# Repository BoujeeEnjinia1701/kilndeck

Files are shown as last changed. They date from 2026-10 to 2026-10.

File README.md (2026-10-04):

# KilnDeck

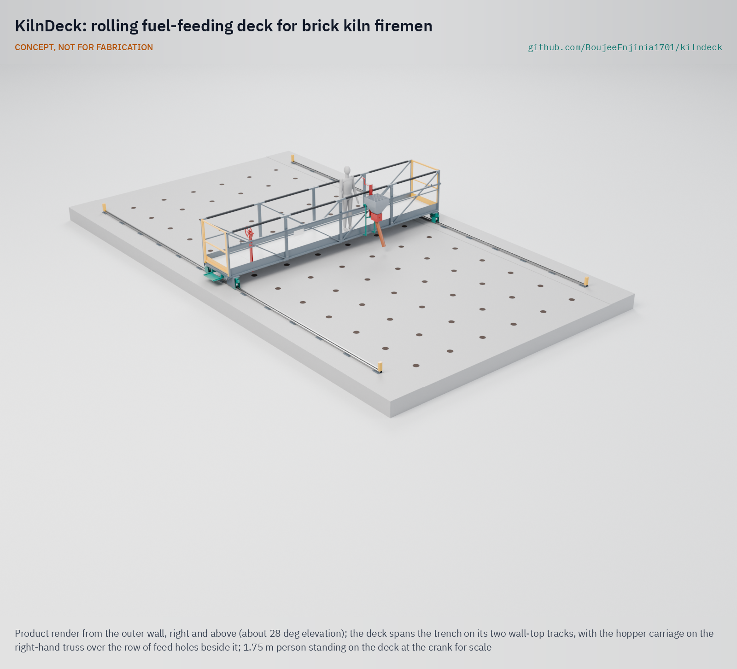
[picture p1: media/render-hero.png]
KilnDeck: rolling fuel-feeding deck for brick kiln firemen


     

**Area:** Sustainable housing · **TRL:** 3 of 9 (proof of concept on paper) · **Value-engineering target:** USD 3,500 (estimated cost of the constructable design USD 2,627) · **Difficulty:** 4 of 5

Carries kiln firemen on a railed rolling deck so they feed fuel without standing on the ash crust over the fire.

> CONCEPT, NOT FOR FABRICATION. KilnDeck is a TRL 3 design on paper: it has not been built or tested.

## Concept rationale

The fireman's job is to feed small amounts of fuel into many holes, over and over. The hazard is where he stands to do it: on the crust above the fire. KilnDeck moves him off the crust. A deck with a guardrail spans the trench from wall to wall and rolls along the kiln on two tracks laid on the wall tops, so nothing rests on the crust. The fireman moves the deck from row to row with a hand wheel, pushes a hopper carriage along the side of the deck to each feed hole, and turns a crank to drop a measured dose through a swing spout. His feet stay on an insulated floor, behind a 1.1 m guardrail.

The metering rotor also serves the kiln. Research in Bangladesh found that training firemen in continuous fuel feeding was part of an intervention that cut fuel use and emissions ([Luby Lab, Stanford](https://lubylab.stanford.edu/brick-kiln-intervention-trial); [Stanford Impact Labs](https://impact.stanford.edu/news/cleaner-brick-manufacturing-bangladesh)). A rotor that gives the same small dose each pocket makes steady feeding easier. Keeping the deck manual and open means kiln owners can have it built by local fabricators without power at the kiln top.

## Burning platform

South Asia has about 51,450 fixed-chimney bull's trench kilns: about 35,000 in India, 11,500 in Pakistan, 4,500 in Bangladesh and 450 in Nepal. In each, two firemen standing on top of the kiln feed fuel through feed holes every 15 to 20 minutes, each round lasting 5 to 10 minutes ([Greentech Knowledge Solutions, 2014](https://www.shareweb.ch/site/Climate-Change-and-Environment/about%20us/about%20gpcc/Documents/01%20Fixed%20Chimney%20Bulls%20Trench%20Kiln%20(FCBTK).pdf)). Firemen interviewed in India described flames burning their trousers and their feet burning in the heat, with wooden slippers as their only protection ([The Migration Story](https://themigrationstory.com/post/braving-the-heat-to-bake-bricks/)).

The worst outcome is a fall into the fire. On 18 June 2026, a 30-year-old labourer named Shahbaz slipped into a burning kiln near Nankana Sahib, Pakistan, and died of his burns at the scene ([The Nation, 2026](https://www.nation.com.pk/18-Jun-2026/laborer-dies-falling-brick-kiln-nankana-sahib)). The workforce is large and poorly protected: brick kilns in India employ more than 23 million workers, many in debt bondage ([Anti-Slavery International](https://www.antislavery.org/what-we-do/past-projects/india-debt-bondage/)).

## Where it could be used

### By industry

| Industry | Use |
| --- | --- |
| Fired clay brick production | Safer fuel feeding on bull's trench and zigzag kilns |
| Kiln upgrade and clean brick programmes | A worker safety add-on that also supports steady, continuous feeding |
| Construction materials supply chains | A documented control buyers and developers can ask brick suppliers to adopt |
| Labour rights and worker health organisations | A practical safety measure to pair with rights work at kilns |
| Engineering and technical education | A field design case in high-temperature structures and hand mechanisms |

### By country or region

| Country or region | Why it matters there |
| --- | --- |
| India | About 35,000 bull's trench kilns ([Greentech, 2014](https://www.shareweb.ch/site/Climate-Change-and-Environment/about%20us/about%20gpcc/Documents/01%20Fixed%20Chimney%20Bulls%20Trench%20Kiln%20(FCBTK).pdf)) and more than 23 million kiln workers ([Anti-Slavery International](https://www.antislavery.org/what-we-do/past-projects/india-debt-bondage/)). |
| Pakistan | About 20,000 kilns of all types employing around 4.5 million workers ([Al Jazeera, 2019](https://www.aljazeera.com/features/2019/10/21/the-spiralling-debt-trapping-pakistans-brick-kiln-workers)), and a fatal fall into a burning kiln in June 2026 ([The Nation](https://www.nation.com.pk/18-Jun-2026/laborer-dies-falling-brick-kiln-nankana-sahib)). |
| Bangladesh | About 4,500 bull's trench kilns ([Greentech, 2014](https://www.shareweb.ch/site/Climate-Change-and-Environment/about%20us/about%20gpcc/Documents/01%20Fixed%20Chimney%20Bulls%20Trench%20Kiln%20(FCBTK).pdf)); the brick sector may cause up to half of the particulate matter in Dhaka, and kilns are the site of active clean-kiln research ([Stanford Impact Labs](https://impact.stanford.edu/news/cleaner-brick-manufacturing-bangladesh)). |
| Nepal | A national survey counted 176,373 manual labourers in brick kilns, of whom 6,229 were in forced labour ([Kathmandu Post, 2021](https://kathmandupost.com/national/2021/01/29/forced-labour-bonded-labour-and-child-labour-prevalent-in-country-s-brick-kilns-sector-new-report-says)). |

## What sparked the idea

The idea came from a short news report. On 18 June 2026, Shahbaz, 30, was working at a brick kiln near Jislani Mor on Warburton Road, Nankana Sahib, when he slipped into the burning kiln; rescue officials said he died at the scene ([The Nation, 2026](https://www.nation.com.pk/18-Jun-2026/laborer-dies-falling-brick-kiln-nankana-sahib)). The report does not say what task he was doing. But on every bull's trench kiln the firemen work standing on the kiln top over the fire ([Greentech, 2014](https://www.shareweb.ch/site/Climate-Change-and-Environment/about%20us/about%20gpcc/Documents/01%20Fixed%20Chimney%20Bulls%20Trench%20Kiln%20(FCBTK).pdf)), and a deck with a guardrail is a direct answer to that exposure.

## Problem

Firemen on bull's trench brick kilns stand and walk on the hot ash crust over the fire to feed fuel through holes in the kiln top, for hours at a time. A slip or a weak spot in the crust can drop them into the burning kiln.

Full problem statement: [docs/01-problem.md](docs/01-problem.md)

## Concept

A walkway deck that spans the trench and rolls along the kiln on two wall-top tracks, carrying the fireman behind a guardrail and a hopper carriage with a hand metering rotor; the fireman moves the deck from row to row with a hand wheel and meters fuel into each feed hole without standing on the ash crust over the fire.

Full design precis: [docs/02-concept.md](docs/02-concept.md) · Requirements: [docs/03-requirements.md](docs/03-requirements.md) · Calculations: [docs/04-calcs/01-sizing.md](docs/04-calcs/01-sizing.md) · Prototype build plan: [docs/05-build-plan.md](docs/05-build-plan.md) · Design decisions: [docs/06-design-decisions.md](docs/06-design-decisions.md)

## Key components

- Wall-top track modules on levelling pads, with end stops
- End trucks with guiding and floating wheels and derailment guards
- Side trusses that are also the 1.1 m guardrails
- Insulated floor panels with a reflective underside
- End rail and inward-opening self-closing gate
- Hand wheel, line shaft and chain drives, with a lock pin as the parking brake
- Hopper carriage with a 52 L hopper, metering rotor, crank and swing spout

## Key numbers (estimates, KND-CAL-001)

- Deck about 800 kg; no piece over 40 kg, so two people carry every part up the kiln.
- Hand wheel force about 64 N to move the loaded deck on level track.
- About 0.49 kg of coal per rotor pocket; the hopper holds about 1.4 feeding rounds.
- Floor top about 48 °C in shade against a crust of about 150 °C; about 74 °C in full summer sun (requirement R7 not met in full sun).

## Building the prototype

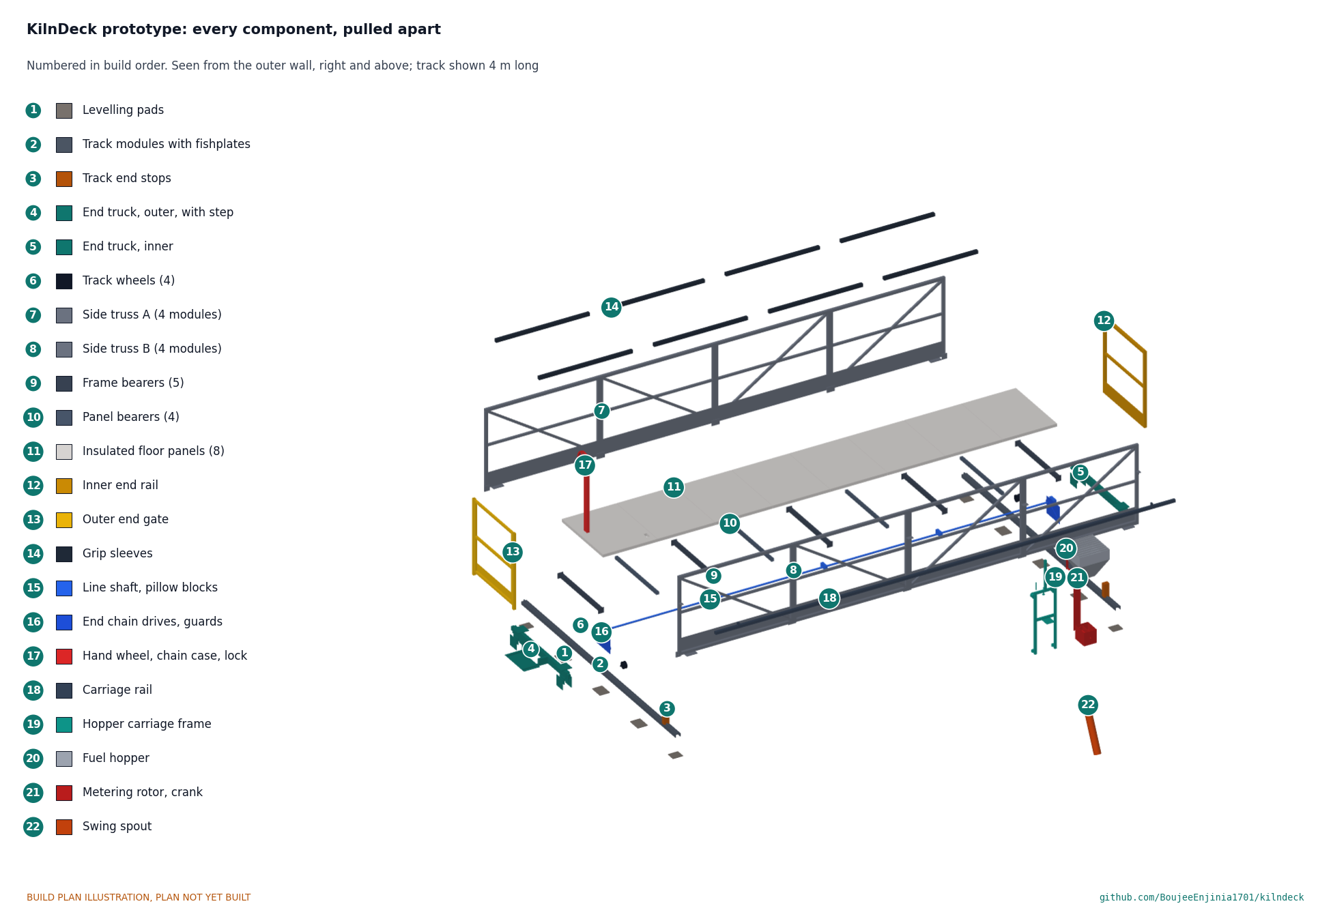
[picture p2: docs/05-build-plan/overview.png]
Every component of the prototype, pulled apart and numbered in build order


The [prototype build plan](docs/05-build-plan.md) (KND-BLD-001) shows how to make each of the 22 groups of parts, with a making sketch, joint close-ups and a picture for every one of the 17 assembly steps. Almost everything is cut, drilled and stick welded from stock steel hollow section, channel and plate; wheels, bearings, chains, the hand wheel and the insulation board are bought. The deck is assembled on trestles over the cold zone of the kiln and rolled to the fire only when complete. It is a plan, not yet built: building and testing to it is TRL 4 work.

## Safety

> **Safety:** KilnDeck carries a person over a burning kiln and has moving parts. It is published as an open engineering reference, not certified equipment. Kiln owners and builders are responsible for their own structural checks and risk assessment.
>
> The tracks must bear on sound kiln walls; a structural survey of each kiln is needed before fitting.
>
> The guardrail is a fall-prevention barrier and must be proof-loaded before use. The gate opens only inward and closes by itself.
>
> End stops and derailment guards keep the deck on its track; the lock pin must be in before feeding at each row.
>
> The chain drives and rotor are guarded; clear the rotor only with the crank, never by hand.
>
> Heat exposure to the fireman remains: the floor reaches about 74 °C in full sun, so heat-resistant footwear, shade, water and rest breaks are still needed. Hot steel surfaces have heat-resistant grip sleeves on the top rails.
>
> Assemble the deck only over the cold zone of the kiln, never over the fire.

## Repository layout

| Folder | Contents |
| --- | --- |
| `docs/` | Problem, concept, requirements, calculations, build plan and design decisions |
| `cad/src/` | build123d Python source, the source of truth for all geometry |
| `cad/step/`, `cad/stl/` | Exported models for FreeCAD, other CAD tools and printing |
| `cad/drawings/` | General arrangement and making sketches |
| `bom/` | Bill of materials |
| `electronics/` | Not used: KilnDeck has no electronics |
| `firmware/` | Not used |
| `media/` | Renders, concept media and the 3D viewer |
| `build-log/` | Dated prototyping notes (from TRL 4) |

## Documentation

Controlled documents follow the portfolio [documentation standard](.kit/STANDARDS.md). Each carries a document ID (KND-PRC-001 for the precis), a version and a revision history. Branded PDFs are built with `python .kit/render.py` and attached to GitHub Releases when a document is tagged, for example `KND-PRC-001/v1.0`.

## Credits

Designed by Amish Chadha at Design Molecule Labs. See [CONTRIBUTORS.md](CONTRIBUTORS.md) for roles. To cite this design, use [CITATION.cff](CITATION.cff) (GitHub shows it as "Cite this repository").

AI assistance (Claude) was used to accelerate prototype documentation and first-pass research. Design direction and all decisions are Amish Chadha's, recorded in this repository's decision records (`docs/decisions/`).

## Licenses

- **Hardware** (CAD, drawings, BOM, electronics): [CERN-OHL-S v2](LICENSE)
- **Software** (firmware, scripts, notebooks): [MIT](LICENSE-SOFTWARE)

A project of the [Design Molecule](https://designmolecule.com) lab.

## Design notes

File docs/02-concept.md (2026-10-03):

---
doc_id: KND-PRC-001
title: KilnDeck design precis
project: KilnDeck
doc_type: Precis
version: "0.2"
status: Draft
date: '2026-10-03'
author: Amish Chadha
license: CERN-OHL-S-2.0
revisions:
- version: "0.1"
  date: '2026-09-30'
  author: Amish Chadha
  change: Initial scaffold
- version: "0.2"
  date: '2026-10-03'
  author: Amish Chadha
  change: TRL 2 and 3 precis; deck spans the trench on wall-top tracks (KND-DDR-001); constructable design (KND-DDR-002); first-order numbers from KND-CAL-001
---

# KilnDeck design precis

Carries kiln firemen on a railed rolling deck so they feed fuel without standing on the ash crust over the fire.

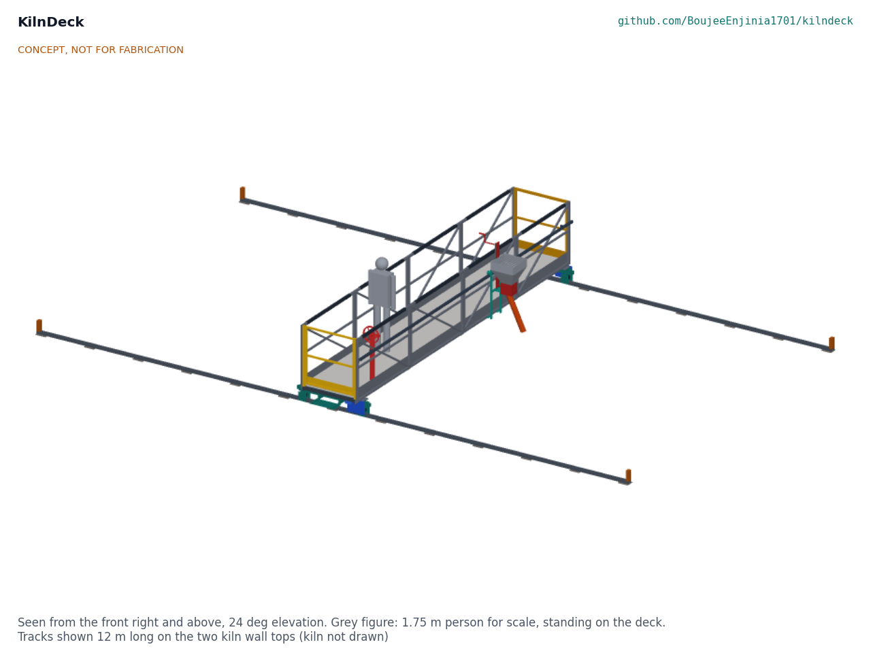
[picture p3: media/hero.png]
Figure 1. KilnDeck on its two wall-top tracks


*Figure 1. The deck spanning the trench on its two wall-top tracks, with the hopper carriage on the right-hand truss and a 1.75 m person on the deck for scale (concept media from the TRL 3 model).*

## How it works

The deck is a walkway bridge that spans the trench from the outer wall to the inner wall and rolls along the kiln on two tracks, one laid on each wall top. Nothing rests on the crust. The fireman boards from the outer wall through a self-closing gate and works inside a 1.1 m guardrail on an insulated floor about 0.4 m above the wall top. He moves the whole deck along the kiln with a hand wheel at the outer end, which drives one wheel at each end through a line shaft so both ends move together; a lock pin in the hand wheel rim holds the deck at each row of feed holes. A hopper of about 52 litres rides on a carriage along the outside of the right-hand truss, over the row of holes beside the deck. He pushes the carriage to a hole, swings the spout over it, and turns a crank above the guardrail: each quarter turn of the metering rotor drops one pocket of fuel, about 0.49 kg of coal (estimate). When the row is fed he rolls the deck about 1 m to the next row. He refills the hopper at the outer end from fuel stocked on the wall top.

## Components

*Table 1. Components (numbers match bom/bom.csv and the exploded view).*

| # | Component | Role |
| --- | --- | --- |
| 1 | Levelling pads | Spread the track load on the wall tops, one every 1.0 m |
| 2 | Track modules | 3 m lengths of channel with a round bar rail, joined by sliding fishplates |
| 3 | Track end stops | Stop the deck at the ends of each track run |
| 4 | End trucks | Carry the deck ends on the tracks, with derailment guards and buffers |
| 5 | Track wheels | U-groove wheels: the outer pair guides, the inner pair floats |
| 6 | Side trusses | Span the trench; their top chords are the top rails of the guardrail |
| 7 | Cross bearers | Carry the floor and make the trusses and floor into stiff U-frames |
| 8 | Insulated floor panels | Standing surface that keeps crust heat off the feet |
| 9 | End rail and gate | Close both ends; the gate opens only inward |
| 10 | Travel drive | Hand wheel, line shaft and chain drives; the lock pin is the parking brake |
| 11 | Carriage rail | Runs along the outside of the right-hand truss |
| 12 | Hopper carriage | Carries the hopper along the deck |
| 13 | Fuel hopper | About 52 L, with a grille that keeps hands from the rotor |
| 14 | Metering rotor and crank | Drops a set dose of fuel per pocket |
| 15 | Swing spout | Directs fuel into the feed hole beside the deck |
| 16 | Grip sleeves | Heat-resistant sleeves on the top rails |

## Key design choices

All decided by Amish under his pre-approval of 2026-10-03 (KND-DDR-001 and KND-DDR-002).

1. **The deck spans the trench and bears only on the walls.** It reaches every hole by moving along the kiln, so no support ever stands on the crust.
2. **Movable track on the straight sides.** 3 m modules, about 33 kg each, are laid ahead of the fire and lifted behind it. The curved ends are not served by this prototype.
3. **The guardrail is the structure.** Two trusses 1.14 m deep carry the floor across 6.6 m, and their top chords are the top rails.
4. **Both ends driven together.** A hand wheel and line shaft stop the long deck skewing on its short wheelbase.
5. **Fuel beside the deck, not under it.** The hopper carriage feeds the next row of holes, so the floor has no openings over the fire and the fireman's feet stay at least 0.6 m from an open hole.
6. **Coal or biomass.** One rotor; the dose is set by the number of pockets.
7. **No piece over 40 kg.** Every module is carried up by two people and bolted together on the kiln, over the cold zone.

## First-order numbers

From KND-CAL-001 (`docs/04-calcs/sizing.py`). All are estimates for a design that has not been built.

*Table 2. First-order numbers.*

| Quantity | Value | Assumption |
| --- | --- | --- |
| Coal per fireman per round | about 30 kg | 30,000 bricks a day, 1.2 MJ per kg of brick, 22 MJ/kg coal, a round every 17.5 min, two firemen |
| Hopper | 52 L, about 42 kg of coal or 13 kg of biomass; 1.4 rounds per fill | Bulk density 0.80 and 0.25 kg/L |
| Dose | about 0.49 kg of coal per pocket, 1.97 kg per turn | 80 % pocket fill |
| Deck mass | about 800 kg; heaviest piece 39 kg | From the model solids |
| Bridge | 11 MPa in the chords, 0.5 mm deflection | 250 kg rated load at mid-span, 1.25 dynamic factor |
| Guardrail | 91 to 100 MPa under a 1 kN push; 150 MPa at the 1.5 kN proof load | S275 steel, yield 275 MPa |
| Hand wheel force | 64 N on level track | Rolling resistance 2 % |
| Wall bearing | 0.15 MPa under a pad | Interim limit 0.20 MPa until the survey |
| Floor top temperature | 34 °C at night, 48 °C in shade, 74 °C in full sun at 45 °C air | Crust 150 °C; the bare crust is the comparison |
| Parts cost | USD 2,627 | Value-engineering target: USD 3,500. Estimated cost of the constructable design: USD 2,627 (USD 873 under the target) |

## Patent design-arounds

From the preliminary patent, trademark and prior-art screen (not legal advice):

- Manual metering rotor only; no motorised feeder.
- Watch any Stanford or BUET patent filing on kiln coal feeders.
- The rotating-disc charger of US1506924A (1924) has expired and is free prior art; KilnDeck uses a pocketed rotor on a horizontal shaft, not a disc.
- Watch items from the preliminary screen: rail heat and wall-top load. Both are now handled in the design (sliding track joints, floating inner wheels, pads under an interim bearing limit).

## Shared blocks

- CalRig proof-load for the guardrail, deck and wall-top tracks at TRL 4.

## Safety

> **Safety:** KilnDeck carries a person over a burning kiln and has moving machinery. The hazards and their controls in this design are: a fall from the deck (1.1 m top rail, knee rail and toe board on all four sides; an inward-opening self-closing gate); the deck running off its track (end stops on every track end, buffers on the trucks, derailment guards either side of each track); the deck moving while someone boards or feeds (lock pin in the hand wheel; the gate is at the hand wheel end); crushed fingers in the drive and rotor (sealed chain case, sheet chain guards, a grille over the hopper, a crank turned by hand with low force); hot surfaces (silicone grip sleeves; an insulated floor, which still reaches about 74 °C in full summer sun, so heat-resistant footwear stays necessary); and the kiln wall giving way (pads under an interim bearing limit and a structural survey of each kiln before fitting).
>
> The deck is assembled over the cold zone of the kiln and rolled to the fire only when complete. Heat exposure to the fireman remains: shade, water and rest breaks are still needed. The guardrail and deck must be proof-loaded before use (TRL 4). This design is published as an open engineering reference. It is not certified equipment.

## Open questions

None for the design; all decisions are recorded in the design decisions register (KND-DEC-001). Facts that depend on the partner kiln (trench width, wall condition, feed hole grid, crust temperature) and on the parts bought are listed there to confirm.

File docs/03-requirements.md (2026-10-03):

---
doc_id: KND-REQ-001
title: KilnDeck requirements
project: KilnDeck
doc_type: Requirements
version: "0.2"
status: Draft
date: '2026-10-03'
author: Amish Chadha
license: CERN-OHL-S-2.0
revisions:
- version: "0.1"
  date: '2026-09-30'
  author: Amish Chadha
  change: Initial scaffold
- version: "0.2"
  date: '2026-10-03'
  author: Amish Chadha
  change: R2 and R4 restated, R12 and R13 added (KND-DDR-001); status on paper from KND-CAL-001 for the constructable design
---

# KilnDeck requirements

On paper, the constructable design meets ten of the thirteen requirements. R7 (floor temperature) is not met in full summer sun, R1 is met on the straight sides of the kiln but not on the curved ends, and R8 is met only against an interim bearing limit until the partner kiln is surveyed. R5 (dose repeatability) can only be judged by weighing doses at TRL 4. Every "met on paper" is a calculation in KND-CAL-001, not a test; verification is TRL 4 work.

*Table 1. Requirements and their status on paper.*

| ID | Requirement | Target | Verification (TRL 4 or later) | Status on paper (KND-CAL-001) |
| --- | --- | --- | --- | --- |
| R1 | Fireman feeds every hole in a round without stepping onto the crust | 0 steps onto the crust per feeding round | Observed trial over at least 20 feeding rounds | Met on the straight sides; **not met on the curved ends**, which this prototype does not serve |
| R2 | Guardrail height and strength (restated) | Top rail 1.1 m (43 in) above the floor with a knee rail at 0.55 m and a 150 mm toe board; holds 1 kN (225 lbf) horizontal at the top rail, proof 1.5 kN without yield | CalRig proof-load test | Met: 81 to 100 MPa at 1 kN, 150 MPa at the proof load (yield 275 MPa) |
| R3 | Deck rated load | 250 kg (550 lb): fireman, full hopper and margin; proof at 1.5 times rated load | Proof load | Met: 18 MPa in the chords at the proof load; 0.5 mm deflection in use |
| R4 | Force to move the loaded deck (restated) | 200 N (45 lbf) or less at the hand wheel rim on level track | Force gauge on the rim | Met: about 64 N level, 128 N on a 2 % grade |
| R5 | Fuel dose per pocket | Repeatable within 15 % of the set dose for dry coal | Weigh 20 doses | To verify at TRL 4; nominal 0.49 kg of coal per pocket |
| R6 | Hopper capacity | At least one full feeding round for one fireman | Measured against the partner kiln's fuel use | Met: 52 L, about 42 kg of coal against about 30 kg a round (1.4 rounds) |
| R7 | Floor temperature at the standing area | 50 °C (122 °F) or less after 6 h on an operating kiln | Contact thermometer log during a firing shift | **Not met in full sun**: about 74 °C at 45 °C air (62 °C at 30 °C air); met at night (34 °C) and in shade (48 °C). The bare crust is about 150 °C |
| R8 | Load on the kiln structure | Below a per-support limit set from a structural survey of the partner kiln | Load cell reading on site | Met against the interim limit of 0.20 MPa (0.15 MPa under a pad); **cannot be confirmed until the survey** |
| R9 | Spout alignment with the feed hole | Within 25 mm (1 in) | Measurement at 10 holes | Met: about 17 mm along the kiln, 10 mm across |
| R10 | Parking brake | Holds the loaded deck on a 5 % grade with no creep | Test on inclined track | Met: lock holds 727 N against 484 N |
| R11 | Cost | Value-engineering target: USD 3,500 for one deck and a demonstration length of track | Costed bill of materials | Estimated cost of the constructable design: USD 2,627 (USD 873 under the target) |
| R12 | Piece mass (new) | Every piece carried up the kiln 40 kg (88 lb) or less | Weigh each piece | Met: heaviest is a truss module at 39.2 kg |
| R13 | Track retention (new) | The deck cannot run off a track end or drop off a track | Push test against the stops; lift test of one wheel | Met by design: end stops, buffers and derailment guards |

## Assumptions

- Kiln walls can carry the track pads without damage; to be confirmed kiln by kiln by a structural survey.
- The trench is about 6.0 m wide, the wall tops are at least 0.6 m wide and level with the crust within 100 mm, and feed holes are on a grid of about 1.0 m (KND-CAL-001, section 1).
- Firemen and owners accept a deck if it does not slow feeding.
- The track is laid in sections on the straight sides and moved with the fire.

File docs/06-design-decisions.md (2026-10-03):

---
doc_id: KND-DEC-001
title: KilnDeck design decisions register
project: KilnDeck
doc_type: Design decisions register
version: "0.1"
status: Draft
date: '2026-10-03'
author: Amish Chadha
license: CERN-OHL-S-2.0
revisions:
- version: "0.1"
  date: '2026-10-03'
  author: Amish Chadha
  change: Register opened; all decisions made under Amish's 2026-10-03 pre-approval
---

# KilnDeck design decisions register

Every design decision still to be made, and every decision made, in one place. Each decision is argued in full in its decision record under `docs/decisions/`; this register is the index Amish works from. The build plan (`docs/05-build-plan.md`) describes the design as it stands and does not list decisions.

## Open decisions

None. All decisions were made under Amish's 2026-10-03 pre-approval.

## To confirm when parts are bought

These are facts that can only be settled with real parts or a real kiln. None changes a decision; each may change a size.

*Table 1. Items to confirm.*

| # | What to confirm | Why it matters | Source |
| --- | --- | --- | --- |
| 1 | Survey of the partner kiln: trench width, wall-top width, level and condition, crust level and temperature, feed hole grid | Sets the track gauge (now 6,600 mm), the deck length, the spout reach and the floor temperature figures | KND-CAL-001, section 1 |
| 2 | Bearing limit of the kiln wall tops from the survey | R8 is met only against the interim 0.20 MPa limit | KND-DDR-002, A2 |
| 3 | Track wheels: rating of at least 500 kg, groove widths 24 and 44 mm, axle length for the drive sprocket | Worst wheel load about 447 kg; the inner wheels must float 12 mm | KND-CAL-001, section 9 |
| 4 | Calcium silicate board: compressive strength at least 0.6 MPa and density near 240 kg/m³ | A heel puts about 0.41 MPa on the board; the panel mass assumes this density | KND-CAL-001, section 8 |
| 5 | Wall thickness and straightness of the SHS bought for the trusses | The truss modules have under 1 kg of margin on the 40 kg limit | KND-CAL-001, section 5 |
| 6 | Hand wheel rim: 12 holes or room to drill them on a 298 mm circle | The lock pin and the 24 mm stopping step depend on it | KND-CAL-001, section 10 |
| 7 | Bulk density and lump size of the partner kiln's coal and biomass | Sets the dose per pocket and the grille gap | KND-CAL-001, section 4 |
| 8 | Silicone grip sleeve to fit a 40 mm square rail, rated to 200 °C | Grip and heat protection on the top rails | BOM line 16 |

## Value engineering

Value-engineering target: USD 3,500 (a hypothetical control target, not a limit). Estimated cost of the constructable design: USD 2,627 (USD 873 under the target). Main cost drivers and savings worth trying:

- The largest lines are the eight floor panels (USD 544, of which about USD 200 is insulation board), the eight truss modules (USD 432), the track for two 12 m runs (USD 368 plus USD 91 of pads and USD 48 of stops), the travel drive (USD 248) and fasteners, paint and consumables (USD 180).
- The track is about a fifth of the cost and is reused as the fire moves, so a longer working run (the fire moves 6 to 10 m a day) would add about USD 51 per 3 m of both tracks.
- Savings worth trying: aluminium tread sheet in place of steel on the floor panels (lighter, but dearer per panel); reclaimed steel channel for the track; a single chain from the hand wheel direct to the outer-end drive if the line shaft can be shortened after the survey.

## Decisions made

*Table 2. Decisions made.*

| Date | Decision | Decided by | Record |
| --- | --- | --- | --- |
| 2026-10-03 | TRL 2 review items D1 to D9: deck spans the trench on two wall-top tracks; movable track on the straight sides; hopper carriage beside the deck; hand wheel and line shaft; 1.1 m guardrail with knee rail and toe board; insulated floor; coal and biomass; first co-design candidates (a clean-kiln programme in Bangladesh, then a kiln owners' association in Punjab, Pakistan, not yet approached); budget, pitch and problem unchanged | Amish, pre-approval of 2026-10-03: "start with the first 14 repos from the list of 29 projects. I pre-approve the batch runs along with any recommendations you come up with. I also accept any cost overruns or variations from the assumed scope cost." | KND-DDR-001 |
| 2026-10-03 | Design for construction, changes C1 to C15: track modules on pads with sliding fishplates, end stops, end trucks with derailment guards, guiding and floating wheels, bolted truss modules, U-frame bearers, insulated floor panels, inward-opening gate, travel drive with lock pin, carriage rail and carriage, hopper grille, rotor with crank over the rail, swing spout, grip sleeves, assembly over the cold zone | Amish, same pre-approval | KND-DDR-002 |
| 2026-10-03 | Wheels rated at least 500 kg; interim wall bearing limit 0.20 MPa until the survey (conservative; relaxed only by a survey); no shade canopy on the first prototype, with R7 reported as not met in full sun and heat-resistant footwear kept (relaxed only by a canopy wind check and logged floor temperatures); curved kiln ends not served | Amish, same pre-approval | KND-DDR-002, A1 to A4 |
| 2026-10-03 | Appearance model departures: a bolt pattern, a nameplate, a load label and a kiln wall and crust strip drawn for the renders only | Amish, same pre-approval | docs/REVIEW.md, TRL 3 section |

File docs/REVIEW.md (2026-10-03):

# Review note: KilnDeck

## Session 2026-09-30: scaffolded

### What was done

- Repository created from kit 1.6.0 at TRL 1, target TRL 2.
- `docs/01-problem.md` (KND-PRB-001 v0.1): problem with cited evidence, users, environment, constraints, prior work, open questions.
- `docs/02-concept.md` (KND-PRC-001 v0.1): how it works, components, patent design-arounds, shared blocks, safety.
- `docs/03-requirements.md` (KND-REQ-001 v0.1): 11 proposed requirements.
- `README.md` with concept rationale, burning platform, where it could be used, and what sparked the idea.

### Next

- Run `/populate` to bring the repo to a strong TRL 2 with concept media.

## Session 2026-10-03: TRL 2 (populate)

Run as the first half of `/to-trl3` on kit 1.7.0, under Amish's 2026-10-03 pre-approval: "start with the first 14 repos from the list of 29 projects. I pre-approve the batch runs along with any recommendations you come up with. I also accept any cost overruns or variations from the assumed scope cost." Every recommendation is therefore recorded as decided, not as "Proposed, awaiting Amish".

### What was done

- Kit 1.7.0 installed (`.kit/`, `.claude/commands/`, root `CLAUDE.md`).
- `docs/01-problem.md` (KND-PRB-001 v0.2): kiln geometry stated as working assumptions, safety note, co-design checklist kept and extended, open questions answered.
- `docs/02-concept.md` (KND-PRC-001 v0.2): how it works, 16 components, seven key design choices, first-order numbers, safety section.
- `docs/03-requirements.md` (KND-REQ-001 v0.2): 13 requirements (R2 and R4 restated, R12 and R13 added), each with a status on paper.
- Concept media from the model: `media/hero.png`, `media/concept-blueprint.png` and `.pdf` (KND-DWG-010), `media/model.glb`, `media/viewer.html`, `media/cutaway.png`, `media/exploded.png`, `media/flow.png` (fuel flow per fireman per round; all values marked as estimates).
- `bom/bom.csv`: 17 lines, every line priced.

### Results

- The concept settled into a deck that spans the 6.6 m between wall-top tracks, so nothing stands on the crust. The scaffold's "small deck on rails along the kiln" could not reach every hole without supports on the crust (KND-DDR-001, D1).

### Requirements not met

- See the TRL 3 section; the TRL 2 statuses were superseded the same day.

### Decisions made under the pre-approval

- KND-DDR-001, D1 to D9 (deck spans the trench; movable track on the straight sides; hopper carriage beside the deck; hand wheel and line shaft; 1.1 m guardrail; insulated floor; coal and biomass; co-design candidates; budget, pitch and problem unchanged).

### Safety concerns

- A person over a burning kiln: falls, the deck leaving its track, pinch points in the drive and rotor, hot surfaces and a wall that gives way. All are addressed in the precis safety section and in the design for construction.

## Session 2026-10-03: TRL 3 (advance and build plan)

Second half of `/to-trl3`, same pre-approval (counts as the TRL 2 approval that `/advance-trl3` needs).

### What was done

- `docs/04-calcs/01-sizing.md` (KND-CAL-001 v0.1) and `docs/04-calcs/sizing.py`: fuel, hopper, rotor, masses, bridge, guardrail, floor panel, wheels and walls, travel and parking, floor temperature, alignment, heat movement and cost, against every requirement.
- `cad/src/model.py`: parametric build123d model of the constructable design with build123d constructability checks (no overlap between any pair of neighbouring parts, carriage clear at both travel limits, every carried piece 40 kg or less). STEP: `cad/step/kilndeck-assembly.step`, `kilndeck-deck.step`, `kilndeck-carriage.step`, `kilndeck-track-module.step`; STL of the last three.
- `cad/drawings/KND-DWG-001` Rev P1: general arrangement (`cad/src/sheets.py`).
- `docs/decisions/0002-design-for-construction.md` (KND-DDR-002): 15 changes and four related choices.
- `cad/src/build_plan_media.py`: overview, 12 making sketches (`cad/drawings/KND-DWG-101` to `112`), 9 joint close-ups and 17 step pictures in `docs/05-build-plan/`.
- `docs/05-build-plan.md` (KND-BLD-001 v0.1) and `docs/06-design-decisions.md` (KND-DEC-001 v0.1).
- `cad/src/product_model.py` (appearance model, views hero, exploded and detail) and the render scenes exported with `.kit/export_views.py` (3 views). Photoreal renders and cards are made on Amish's Mac.
- `project.yaml`: trl 3, trl_target 3, design_state constructable, trl_evidence listed; `budget_usd` unchanged at 3,500.
- README: leads with `media/render-hero.png` (made on the Mac), prototype build plan link, "Building the prototype" section.

### Results

*Table 1. Key numbers (KND-CAL-001).*

| Quantity | Value |
| --- | --- |
| Deck mass | about 797 kg; carriage about 48 kg empty; 12 m of track per wall with pads and stops about 358 kg |
| Heaviest piece | truss module, 39.2 kg |
| Bridge, truss B in use | 11 MPa, 0.5 mm deflection; proof 18 MPa |
| Guardrail, 1 kN | 81 to 100 MPa; 150 MPa at the 1.5 kN proof |
| Worst wheel load | about 447 kg (wheels rated 500 kg or more) |
| Wall bearing | 0.150 MPa against an interim 0.20 MPa |
| Hand wheel force | 64 N level |
| Lock on a 5 % grade | holds 727 N against 484 N |
| Hopper | 52 L, about 42 kg of coal, 1.4 rounds |
| Dose | about 0.49 kg of coal per pocket (estimate) |
| Floor top | 34 °C night, 48 °C shade, 74 °C full sun at 45 °C air (crust 150 °C) |
| Cost | Value-engineering target: USD 3,500. Estimated cost of the constructable design: USD 2,627 (USD 873 under the target) |

### Requirements not met

- **R7** (floor 50 °C or less) is not met in full summer sun: about 74 °C at 45 °C air and 62 °C at 30 °C air. It is met at night and in shade. The sun sets the daytime figure, not the kiln.
- **R1** is met on the straight sides only; the curved ends of the kiln are not served by this prototype.
- **R8** is met only against the interim 0.20 MPa bearing limit; it cannot be confirmed until the partner kiln is surveyed.
- **R5** (dose repeatability) can only be judged by weighing doses at TRL 4.

### Decisions made under the pre-approval

- KND-DDR-002, C1 to C15 (design for construction) and A1 to A4 (wheel rating, interim wall limit, no canopy on the first prototype, curved ends not served).
- Appearance model departures from `model.py`, decided under the same pre-approval: M12 splice bolt heads, a nameplate and a 250 kg load label on truss B, a strip of kiln (brick wall tops, ash crust, feed holes) and a 1.75 m mannequin on the deck. They are drawn for the renders only.
- The design decisions register has no open decisions; eight items are listed to confirm when parts are bought or the kiln is surveyed.

### Build plan findings

- The scaffold concept could not be built as described: a small deck on rails along the crust needs supports on the crust. Spanning the trench solved it and made the guardrail the main structure.
- Pushing a 6.6 m deck from one end on a 1.2 m wheelbase risks skewing and jamming, so both ends are driven by one hand wheel through a line shaft.
- The deck grows about 4.8 mm across the trench when warm, and the walls are not built to a gauge; one pair of wheels has a wide groove so the deck floats 12 mm.
- The 40 kg piece limit, not strength, sets the truss modules; they have under 1 kg of margin.
- The deck must be assembled over the cold zone of the kiln and rolled to the fire complete; there is no safe way to assemble it over the fire.

### Design changes made for construction (2026-10-03)

C1 track modules on pads with slotted fishplates; C2 track end stops; C3 end trucks with derailment guards, buffers and boarding step; C4 guiding and floating U-groove wheels; C5 bolted truss modules as the guardrail; C6 U-frame bearers; C7 insulated floor panels; C8 inner end rail and inward-opening gate; C9 hand wheel, line shaft, chain drives and lock pin; C10 carriage rail and carriage; C11 hopper grille; C12 rotor with chain to a crank over the rail; C13 swing spout on a turned collar; C14 grip sleeves; C15 assembly over the cold zone. Full table in KND-DDR-002.

### Safety concerns

- Falls from the deck: 1.1 m top rail, knee rail and toe board on all sides, inward-opening self-closing gate. Proof-load before use (TRL 4).
- The deck leaving its track: end stops, buffers and derailment guards.
- The kiln wall giving way: interim bearing limit and a survey of every kiln before fitting.
- Pinch points: sealed chain case, chain guards, hopper grille; the rotor is cleared only with the crank.
- Heat: the floor reaches about 74 °C in full sun, so heat-resistant footwear stays necessary; shade, water and rest breaks are still needed.
- Assembly: only over the cold zone, never over the fire.

### Check

- `python .kit/render.py` and `python .kit/render.py --check`: see the session result; the missing `media/render-hero.png` (and cards) warning is expected until the Mac render.
- `python .kit/drawing.py --check-text cad/drawings/*.svg media/concept-blueprint.svg`: no overlaps.

### Recommended next step

- Amish's review, then the photoreal renders and cards on the Mac.
- Before TRL 4 (on hold by the portfolio phase): approach the first co-design candidate and survey one kiln, which settles the gauge, the wall bearing limit and the crust temperature.

## 2026-10-03: photoreal renders

Rendered with Blender Cycles on Amish's Mac from `cad/src/product_model.py`; captioned with `.kit/photo_caption.py`; `media/card.png` and `media/social-preview.png` made with `.kit/cards.py`. Views: hero, exploded, detail. image_qc passes and `render.py --check` has no FAIL.

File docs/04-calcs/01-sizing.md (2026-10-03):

---
doc_id: KND-CAL-001
title: KilnDeck sizing and first-principles checks
project: KilnDeck
doc_type: Calculation note
version: "0.1"
status: Draft
date: '2026-10-03'
author: Amish Chadha
license: CERN-OHL-S-2.0
revisions:
- version: "0.1"
  date: '2026-10-03'
  author: Amish Chadha
  change: First TRL 3 sizing note on the constructable design (KND-DDR-002), against every requirement
---

# KilnDeck sizing and first-principles checks

On paper the deck is strong, stiff and light enough, easy to move and cheaper than the value-engineering target, but its floor is too hot in full summer sun. Ten of the thirteen requirements in KND-REQ-001 are met on paper. R7 (floor at 50 °C or less) is not met in full sun at 45 °C air, where the floor top reaches about 74 °C, although that is about half the 150 °C of the crust the fireman stands on today. R1 is met on the straight sides only. R8 is met only against an interim bearing limit until the partner kiln is surveyed, and R5 (dose repeatability) needs a weighing trial at TRL 4. The parts cost is USD 2,627. Value-engineering target: USD 3,500. Estimated cost of the constructable design: USD 2,627 (USD 873 under the target).

Every number in this note is printed by `docs/04-calcs/sizing.py` (run from the repo root: `python docs/04-calcs/sizing.py`). The script reads the geometry from `PARAMS` and `levels()` in `cad/src/model.py`, takes masses from the model solids and reads prices from `bom/bom.csv`, so the model, the drawing KND-DWG-001, the BOM and this note agree. All values are first-principles estimates. Nothing here is measured.

## 1. Assumptions

*Table 1. Assumptions. Kiln values are working assumptions until the survey of the partner kiln.*

| Quantity | Value | Basis |
| --- | --- | --- |
| Kiln output | 30,000 bricks a day | Midpoint of 20,000 to 50,000 ([Greentech, 2014](https://www.shareweb.ch/site/Climate-Change-and-Environment/about%20us/about%20gpcc/Documents/01%20Fixed%20Chimney%20Bulls%20Trench%20Kiln%20(FCBTK).pdf)) |
| Fired brick | 3.0 kg | 230 x 115 x 75 mm at about 1.5 kg/L |
| Specific energy | 1.2 MJ per kg of fired brick | Assumption for a fixed-chimney kiln |
| Coal | 22 MJ/kg; bulk 0.80 kg/L | Assumption |
| Biomass | bulk 0.25 kg/L | Chopped stalks or husk, assumption |
| Feeding | every 17.5 min by two firemen; 18 holes per fireman per round | Greentech (15 to 20 min); 3 rows of 6 holes is an assumption |
| Trench and track | trench 6,000 mm; track centres 6,600 mm | Assumption until the survey |
| Feed holes | 150 mm across, about 1,000 mm apart | Assumption |
| Crust surface | 150 °C, 250 °C at hot spots | Assumption, to be measured with a thermal camera |
| Air | 45 °C summer day, 30 °C night; sun 1,000 W/m² | Typical South Asian summer |
| Live load | fireman 100 kg; rated 250 kg; dynamic factor 1.25 | R3 |
| Rolling resistance | 2 % (ball-bearing wheels on a dusty bar) | Assumption |
| Friction of a locked wheel | 0.15 (dusty steel on steel) | Assumption |
| Chain efficiency | 85 % | Assumption |
| Wall bearing | interim limit 0.20 MPa under a pad | Conservative for old brick in mud or lime mortar, until the survey (KND-DDR-002, A2) |
| Steel | S275, yield 275 MPa, E = 210 GPa | |

## 2. Fuel per round

Coal per day is 30,000 x 3.0 kg x 1.2 MJ/kg / 22 MJ/kg = about 4,909 kg. With a round every 17.5 min there are about 82 rounds a day, so each round takes about 59.7 kg, or about 29.8 kg per fireman and about 1.66 kg per hole.

## 3. Hopper (R6)

The hopper holds about 52.1 L below the grille: about 41.7 kg of coal or about 13.0 kg of biomass. One fill covers about 1.4 coal rounds for one fireman. **R6 met** for coal. With biomass the fireman refills every round, which the outer-end refill point allows.

## 4. Metering rotor (R5)

The four-pocket rotor (160 mm across, 200 mm long, 40 mm hub, 8 mm vanes) moves about 3.08 L per turn, 0.770 L per pocket. At 80 % fill that is about 0.49 kg of coal per pocket (1.97 kg per turn) or about 0.15 kg of biomass. A hole needs about 3.4 pockets of coal a round. The largest lump that passes a pocket is about 40 mm, and the grille gaps are 44 mm. **R5** (repeatability within 15 %) cannot be judged on paper; it is weighed at TRL 4.

## 5. Masses (R12)

*Table 2. Masses from the model solids (kg).*

| Item | Mass |
| --- | --- |
| Deck (trucks, wheels, trusses, bearers, floor, end frames, grips, drive, carriage rail) | about 797 |
| Hopper carriage, hopper, rotor and spout, empty | about 48 |
| Track, pads and stops for two 12 m runs | about 358 |
| Heaviest pieces carried up | truss module B 39.2; truss module A 38.8; outer end truck 37.8; track module 33.4; floor panel 30.4; frame bearer 6.9 |

**R12 met**: no piece is over 40 kg. The truss modules have under 1 kg of margin, so heavier tube than specified must not be substituted.

## 6. Bridge (R3)

Each side truss is checked as a simply supported beam over the 6,600 mm track centres, with chords 1,143 mm apart (second moment about 29,024 cm⁴ per truss). Truss B takes half the deck's own weight (0.537 N/mm), the carriage with a full hopper (about 90 kg) and half the fireman, all at mid-span with a 1.25 dynamic factor: 1,717 N.

*Table 3. Bridge results.*

| Case | Bending moment | Chord force | Chord stress | Deflection |
| --- | --- | --- | --- | --- |
| Truss A in use | 3.93 kN m | 3.44 kN | 8 MPa | 0.4 mm |
| Truss B in use | 5.76 kN m | 5.04 kN | 11 MPa | 0.5 mm (span/13,143) |
| Truss B, proof 1.5 x 250 kg | 8.99 kN m | | 18 MPa | |

Deflections include a 1.3 factor for the shear deformation of the truss. The top chord could buckle between U-frames (1,725 mm) at 71.0 kN against 5.04 kN, a ratio of 0.07. Each M12 splice bolt near the bottom chord carries about 2.52 kN in tension. **R3 met** with a large margin; the trusses are sized by the guardrail load and the 40 kg piece limit, not by the bridge.

## 7. Guardrail (R2)

A 1 kN horizontal push on the top rail is checked in three places. Between posts (clear span 1,645 mm, simply supported) the top chord sees 81 MPa. At a splice, the two bolted end verticals act together as a cantilever 1,143 mm tall: 91 MPa and 9.4 mm of movement at the rail. At the deck ends, the truss end vertical and the end rail or gate post bend together: 100 MPa. The 1.1 kN m at the foot of a splice post passes into the frame bearer through its bolted end plate, about 7.1 kN in each of the two tension bolts (M12 8.8 holds about 48 kN). At the 1.5 kN proof load the stresses are 136 and 150 MPa, below the 275 MPa yield. **R2 met**.

## 8. Floor panel

A 1.5 kN heel load in the middle of a panel spanning 858 mm between bearers puts 98 MPa in the two 40 x 40 x 4 edge angles and deflects them 1.0 mm. Under a 60 mm square heel spread by the 2 mm top sheet, the board sees about 0.41 MPa; the board's compressive strength is to be confirmed with the supplier (KND-DEC-001).

## 9. Wheels, track and walls (R8, R13)

The worst wheel load is about 4,387 N (447 kg), on the side B wheel of the truck nearest the carriage when it is at its travel limit, with the dynamic factor. The wheels are specified at 500 kg or more. The track channel between pads 1.0 m apart (UPN 80 bending about its weak axis, bar ignored) sees 172 MPa and deflects 2.24 mm under that wheel. The pad below carries about 4,496 N, a bearing pressure of about 0.150 MPa against the interim limit of 0.20 MPa. **R8 met against the interim limit only**; it is confirmed when the survey sets the real limit.

Across the kiln the deck cannot tip: the restoring moment of its own weight about the side B wheel line is 4.69 kN m against 0.36 kN m from the carriage. **R13** is met by the end stops, buffers and derailment guards (KND-DDR-002, C2 and C3).

## 10. Travel and parking (R4, R10)

The loaded deck (deck, carriage, full hopper and fireman) weighs about 9,687 N. At 2 % rolling resistance it takes about 194 N to move, which the 45 mm tread radius and the 160 mm hand wheel radius, through 1:1 chains at 85 %, turn into about 64 N at the rim on level track and about 128 N on a 2 % grade. **R4 met**. One turn moves the deck about 283 mm, and the 12 lock holes in the rim give a step of about 24 mm. The 25 mm line shaft sees 2.8 MPa in torsion. The carriage takes about 27 N to push along its rail.

On a 5 % grade the deck pulls 484 N downhill. With the lock pin in, the two driven wheels are locked and carry about half the weight; sliding them takes about 727 N at a friction of 0.15. **R10 met** with a factor of about 1.5.

## 11. Floor temperature (R7)

A steady heat balance through one square metre of floor: the crust radiates to the aluminium underside (emissivity 0.3 when dusty, against 0.9 for the crust) and hot air under the deck adds convection at 5 W/m²K; heat crosses 37 mm of calcium silicate board (0.065 W/mK); the top sheet absorbs half the sun and loses heat to the air at 10 W/m²K and by radiation to the sky.

*Table 4. Floor top temperature.*

| Case | Floor top | Underside | Heat through | Bare crust |
| --- | --- | --- | --- | --- |
| Night, nominal crust, 30 °C air | 34 °C | 104 °C | 123 W/m² | 150 °C |
| Summer day, shaded, 45 °C air | 48 °C | 110 °C | 109 W/m² | 150 °C |
| Summer day, full sun, 45 °C air | 74 °C | 114 °C | 71 W/m² | 150 °C |
| Hot spot, full sun | 81 °C | 195 °C | 201 W/m² | 250 °C |
| 30 °C day, full sun | 62 °C | 109 °C | 83 W/m² | 150 °C |

**R7 not met in full sun.** The sun, not the kiln, sets the floor temperature by day: in shade the floor holds 48 °C. The design keeps no canopy on the first prototype (KND-DDR-002, A3), and the fireman keeps heat-resistant footwear. The edges of each panel, where the steel frame joins top and bottom, will run hotter than these figures.

## 12. Spout alignment (R9)

Along the kiln the deck stops within half a lock step (12 mm) plus about 5 mm of chain play: about 17 mm. Across the kiln the carriage is pushed by eye to the hole and clamped: about 10 mm. A 100 mm spout over a 150 mm hole leaves 25 mm each side. **R9 met** on paper.

## 13. Heat movement

A 3 m track module grows about 3.6 mm when it warms by 100 K; the joints have 6 mm gaps and slotted fishplates. The deck grows about 4.8 mm across the trench when it warms by 60 K; the inner wheels float 12 mm either way.

## 14. Cost (R11)

The 17 lines of `bom/bom.csv` total USD 2,626.97 (steel at USD 1.30/kg from the model masses; bought parts at regional retail estimates; fabrication labour not included). Value-engineering target: USD 3,500. Estimated cost of the constructable design: USD 2,627 (USD 873 under the target). **R11 met** against the target.

> **Safety:** These are first-principles estimates. The guardrail, deck and track must be proof-loaded (CalRig) and the kiln wall surveyed by a competent person before anyone stands on the deck over a fire. Nothing in this note authorises use.

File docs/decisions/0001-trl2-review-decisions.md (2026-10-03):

---
doc_id: KND-DDR-001
title: KilnDeck TRL 2 review decisions
project: KilnDeck
doc_type: Design decision record
version: "0.1"
status: Draft
date: '2026-10-03'
author: Amish Chadha
license: CERN-OHL-S-2.0
revisions:
- version: "0.1"
  date: '2026-10-03'
  author: Amish Chadha
  change: TRL 2 review items decided under Amish's 2026-10-03 pre-approval
---

# 0001: TRL 2 review decisions

- **Date:** 2026-10-03
- **Status:** decided. Decided by Amish under his pre-approval of 2026-10-03: "start with the first 14 repos from the list of 29 projects. I pre-approve the batch runs along with any recommendations you come up with. I also accept any cost overruns or variations from the assumed scope cost."

## Context

The scaffold (KND-PRB-001, KND-PRC-001 and KND-REQ-001, all v0.1) left five open questions and described the deck only in outline: "a pair of rails runs along the top of the kiln, carried on supports that bear on the kiln's structural walls", with a small deck that the fireman pushes from hole to hole. Populating the concept to TRL 2 meant settling how the deck reaches every feed hole while bearing only on the walls. Amish pre-approved every recommendation in this batch, so each item below is decided, not proposed. Items that touch safety take the conservative option and say what evidence would relax it. Partners and regions are the first candidates to approach, not agreements.

## Options considered

*Table 1. Options.*

| # | Item | Options |
| --- | --- | --- |
| D1 | How the deck reaches every hole | (a) small deck on rails laid along the crust on cross beams; (b) deck that spans the trench wall to wall and rolls along the kiln on one track per wall top; (c) fixed bridges moved by hand |
| D2 | Track layout | (a) full circuit round the kiln; (b) movable sections on the straight sides, leapfrogged ahead of the fire |
| D3 | How fuel reaches the holes | (a) hopper on the deck floor with a chute through the floor; (b) hopper on a carriage that runs along the outside of one side truss and feeds the row beside the deck |
| D4 | How the deck is moved | (a) pushed from the wall top at one end; (b) hand wheel on the deck driving one wheel at each end through a line shaft |
| D5 | Guardrail height | (a) 1.0 m as in the scaffold R2; (b) 1.1 m top rail with knee rail and toe board, after EN ISO 14122-3 |
| D6 | Floor | (a) plain steel chequer plate; (b) insulated panel: steel top, calcium silicate board, reflective aluminium underside |
| D7 | Fuels | (a) coal only; (b) coal and chopped biomass, with the dose set by the number of pockets |
| D8 | Co-design partner | Clean-kiln programmes and kiln owners' associations in Pakistan, India, Bangladesh and Nepal |
| D9 | Budget, pitch and problem | Keep or change |

## Decision

*Table 2. Items decided on 2026-10-03.*

| # | Item | Decision | Why |
| --- | --- | --- | --- |
| D1 | Reaching every hole | (b): the deck spans the trench and rolls along the kiln on two wall-top tracks. It is still the railed rolling deck of the pitch; it now stands only on the walls | Option (a) puts track supports on the crust or needs cross beams across the trench anyway; (b) bears on the walls alone and reaches every hole in the trench by moving along the kiln |
| D2 | Track layout | (b): 3 m track modules on the straight sides, laid ahead of the fire and lifted from behind it (the fire moves 6 to 10 m a day); the curved ends are not served by this prototype | Lighter, cheaper and needs no curved track; a full circuit is a later option |
| D3 | Fuel delivery | (b): hopper carriage on side B feeding the row of holes 1.2 m from the deck centre line | Keeps the floor whole (no slot over the fire) and keeps the fireman's feet at least 0.6 m from an open hole |
| D4 | Moving the deck | (b): hand wheel and line shaft driving one wheel at each end, so both ends move together and the 6.6 m deck cannot skew and jam | Pushing one end of a long deck on a short wheelbase risks skewing; the fireman also stays on the deck |
| D5 | Guardrail | (b): top rail 1.1 m above the floor, knee rail at 0.55 m, toe board 0.15 m; R2 restated | Conservative: this is a fall-prevention barrier over a fire. No evidence is expected to relax it; the higher rail costs almost nothing |
| D6 | Floor | (b): insulated panels with a reflective underside | The crust is estimated at 150 °C; plain plate would pass most of that to the feet |
| D7 | Fuels | (b): both. The rotor gives about 0.49 kg of coal or about 0.15 kg of biomass per pocket (estimates); the fireman sets the dose by counting pockets | Kilns switch fuels; one rotor that works with both keeps the design simple |
| D8 | Co-design partner | First candidate to approach: a clean-kiln research programme in Bangladesh already running fuel-feeding training (for example the Stanford and BUET kiln team). Second: a kiln owners' association in Punjab, Pakistan. Neither has been approached | Training in continuous feeding is already in place there, and the fall hazard is documented in Punjab |
| D9 | Budget, pitch and problem | No change. `budget_usd` stays at USD 3,500 as the value-engineering target | The constructable design is estimated at USD 2,627 |

## Consequences

- KND-PRB-001, KND-PRC-001 and KND-REQ-001 are revised to v0.2. R2 is restated (1.1 m top rail, knee rail, toe board), R4 is restated as the force on the hand wheel rim, and R12 (no piece over 40 kg) and R13 (the deck cannot run off its track) are added.
- The open questions of KND-PRB-001 are answered in the precis: sections, not a full circuit (D2); rail heat handled by sliding fishplate joints and a floating inner wheel (KND-DDR-002); coal and biomass (D7). What firemen think of the deck stays open for the co-design partner, as research rather than a design decision.
- The kiln dimensions in the calculation note (trench width, wall-top width, feed hole grid, crust temperature) are assumptions until a survey of the partner kiln.
- TRL 4 is on hold by the portfolio phase. Nothing in this record authorises building or testing.

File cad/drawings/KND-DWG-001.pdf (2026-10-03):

CONCEPT, NOT FOR FABRICATION | KilnDeck · github.com/BoujeeEnjinia1701/kilndeck

FRONT VIEW
Scale 1:100; looking at the front (along +Y)

TOP VIEW
Scale 1:100; looking down (along -Z)

RIGHT VIEW
Scale 1:100; looking at the right side (along -X)

3000

7170 1808

ISOMETRIC VIEW
Not to scale; track shown 3 m long; seen from the front right and above, about 30 deg elevation

KEY DIMENSIONS (MM) AND DATA
Track centres 6600 across a 6000 trench (to survey) Deck 6900 long, 1160 wide over the trusses
Wheelbase 1200; 100 mm U-groove wheels on 20 mm bar Rail top 75, floor 393 above the wall top
Top rail 1100, knee rail 550, toe board 150 above floor Four truss modules a side, 1725 long, 6 x M12 per splice Floor: 8 panels, 2 steel / 37 board / 1 aluminium
Line shaft 25 dia at 250; hand wheel 320 dia
Carriage rail top 1143; carriage travel +/-2900
Hopper 450 x 450, about 52 L; rotor 160 dia x 200 Spout outlet 1225 from deck centre line, 150 up Crank at 1653, over the top rail
Deck about 800 kg; no piece over 40 kg PRELIMINARY, NOT FOR FABRICATION
REV | DESCRIPTION | DATE | BY
P1 | Preliminary GA from the constructable TRL 3 model (KND-DDR-002) | 2026-10-03 | AC
KILNDECK | github.com/BoujeeEnjinia1701/kilndeck

## Rolling fuel-feeding deck: general arrangement

DRAWING NO.
KND-DWG-001

REV
P1

SHEET
1 of 1

SIZE

## ANSI B

SCALE
1:100

UNITS
mm
PROJECTION | DATE
2026-10-03

DRAWN
Amish Chadha

MATERIAL / NOTES
S275 hollow sections, channel and plate; calcium silicate board; aluminium sheet. See bom/bom.csv
Licensed CERN-OHL-S-2.0 · Design Molecule Lab · designmolecule.com | Generated from cad/src; do not edit by hand

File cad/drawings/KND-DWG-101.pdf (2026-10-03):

### BUILD PLAN SKETCH, PLAN NOT YET BUILT KilnDeck · github.com/BoujeeEnjinia1701/kilndeck

FRONT VIEW
Scale 1:20; looking at the front (along +Y)

TOP VIEW
Scale 1:20; looking down (along -Z)

RIGHT VIEW
Scale 1:20; looking at the right side (along -X)

3103

150 75

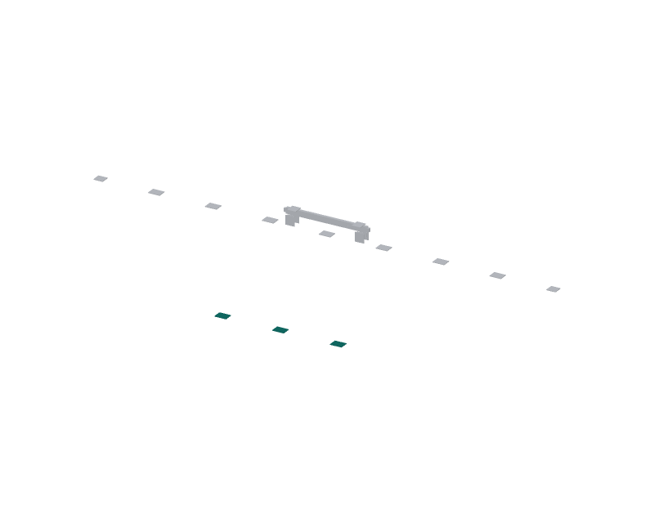
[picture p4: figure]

WHERE IT GOES
This part in colour, its neighbours in grey

HOW TO MAKE IT AND HOW IT FITS
Make eight. Saw UPN 80 channel 3,000 mm long, square ends. It lies flanges down: the flat 80 mm web on top, flanges on the pads. Rail: 20 mm round bar along the middle of the web, stitch welded both sides, 40 mm welds every 250 mm. Grind the joint ends flush. End modules: stop the bar 70 mm short of the outer end. Fishplates: 6 x 30 x 200 mm flat, one each side across each joint, two M12 bolts in 14 x 24 mm slots so the joint can slide 6 mm. Pads: 200 x 150 x 10 mm plate, one every 1,000 mm and under each joint, bedded level on a thin lime-sand mortar on the wall top.
End stops: 8 mm plate box 60 x 80 x 200 mm, rubber face, two M12 bolts down through the web at each track end.
Check: bar straight within 2 mm over 3 m; tops of the two wall tracks level with each other within 5 mm.
REV | DESCRIPTION | DATE | BY
P1 | Making sketch for the prototype build plan | 2026-10-03 | AC
KILNDECK | github.com/BoujeeEnjinia1701/kilndeck

## KilnDeck track module (make 8) with pads: making sketch

DRAWING NO.
KND-DWG-101

REV
P1

SHEET
1 of 1

SIZE

## ANSI B

SCALE
1:20

UNITS
mm
PROJECTION | DATE
2026-10-03

DRAWN
Amish Chadha

MATERIAL / NOTES
UPN 80 channel 3,000 mm; 20 mm round bar; 6 mm flat; 10 mm plate; S275
Licensed CERN-OHL-S-2.0 · Design Molecule Lab · designmolecule.com | Generated from cad/src; do not edit by hand

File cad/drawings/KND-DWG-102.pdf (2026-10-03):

### BUILD PLAN SKETCH, PLAN NOT YET BUILT KilnDeck · github.com/BoujeeEnjinia1701/kilndeck

FRONT VIEW
Scale 1:10; looking at the front (along +Y)

TOP VIEW
Scale 1:10; looking down (along -Z)

RIGHT VIEW
Scale 1:10; looking at the right side (along -X)

1480

500 270

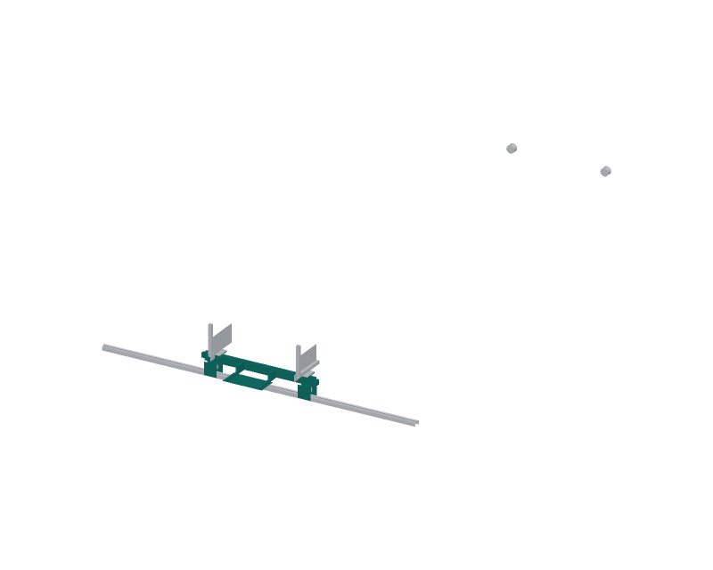
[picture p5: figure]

WHERE IT GOES
This part in colour, its neighbours in grey

HOW TO MAKE IT AND HOW IT FITS
Beam: RHS 100 x 50 x 4 mm, 1,400 mm long, the 100 mm side upright. Fork plates: 8 mm, 120 x 100 mm, two per wheel, 600 mm each side of the middle, hanging under the beam, 3 mm clear of each wheel face; 21 mm axle holes 70 mm below the beam. Inner truck: forks 70 mm apart for the wide-groove wheels; outer truck: 50 mm apart.
Seats: 10 mm plate 150 x 160 mm on top, 560 mm each side of the middle, four 14 mm holes outside the beam for the truss feet. Derailment guards: 6 mm plate 160 x 160 mm either side of the track, 24 mm clear of the channel, bottom edge 30 mm above the wall top. Shaft hole: 32 mm through both walls, 380 mm right of the middle, 60 mm up from the beam bottom. Rubber buffers on both ends. Outer truck only: 500 x 240 x 4 mm chequer step on two brackets. Check: the four axle holes lie square and level within 1 mm.
REV | DESCRIPTION | DATE | BY
P1 | Making sketch for the prototype build plan | 2026-10-03 | AC
KILNDECK | github.com/BoujeeEnjinia1701/kilndeck

## KilnDeck end truck (make 2; the outer one with the step): making sketch

DRAWING NO.
KND-DWG-102

REV
P1

SHEET
1 of 1

SIZE

## ANSI B

SCALE
1:10

UNITS
mm
PROJECTION | DATE
2026-10-03

DRAWN
Amish Chadha

MATERIAL / NOTES
RHS 100 x 50 x 4 mm; 8, 10 and 6 mm plate; 4 mm chequer plate; S275
Licensed CERN-OHL-S-2.0 · Design Molecule Lab · designmolecule.com | Generated from cad/src; do not edit by hand

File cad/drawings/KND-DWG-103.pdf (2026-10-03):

### BUILD PLAN SKETCH, PLAN NOT YET BUILT KilnDeck · github.com/BoujeeEnjinia1701/kilndeck

FRONT VIEW
Scale 1:25; looking at the front (along +Y)

TOP VIEW
Scale 1:25; looking down (along -Z)

RIGHT VIEW
Scale 1:25; looking at the right side (along -X)

155

1765 1223

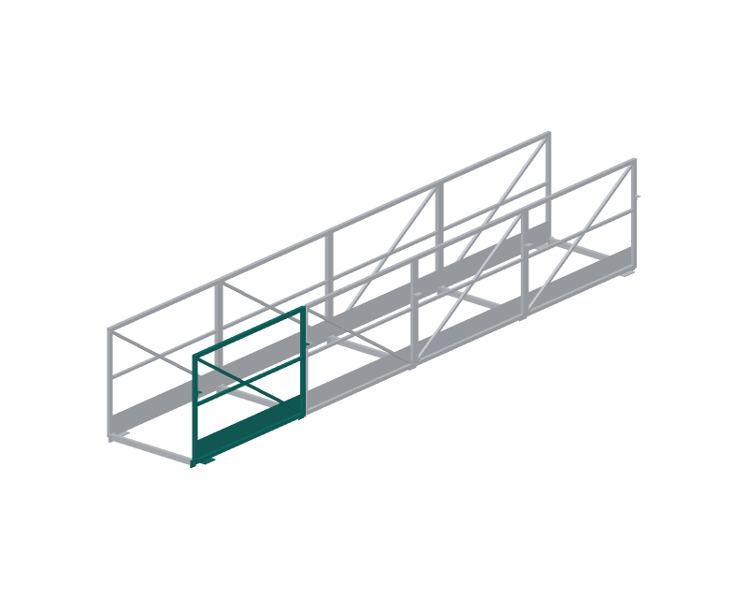
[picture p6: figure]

WHERE IT GOES
This part in colour, its neighbours in grey

HOW TO MAKE IT AND HOW IT FITS
Make eight, four a side, on a flat jig. Drawn: side B end module. Chords: SHS 40 x 40 x 3, 1,725 mm; centres 1,143 mm apart. The top chord is the top rail, 1,100 mm above the floor.
Verticals: SHS 40 x 40 x 4, 1,103 mm between the chords, flush with each end. Diagonal and knee rail: SHS 30 x 30 x 3; knee rail 550
mm above the floor. All joints welded all round.
Toe board: 2 mm sheet, 150 mm above the floor, on the inner edge. Splice holes: three pairs of 13 mm holes through each end vertical, at 60, 560 and 1,060 mm up, for six M12 bolts per splice.
Bearer cleats: 8 x 80 x 80 mm plate on the chord's inner face at each end, reaching 40 mm below it, four 13 mm holes.
End modules: 10 mm foot plate 150 x 160 mm under the chord. Side B: 6 mm shelf brackets for the carriage rail on both verticals. Check: flat within 3 mm; about 39 kg (two people).
REV | DESCRIPTION | DATE | BY
P1 | Making sketch for the prototype build plan | 2026-10-03 | AC
KILNDECK | github.com/BoujeeEnjinia1701/kilndeck

## KilnDeck side truss module (make 8): making sketch

DRAWING NO.
KND-DWG-103

REV
P1

SHEET
1 of 1

SIZE

## ANSI B

SCALE
1:25

UNITS
mm
PROJECTION | DATE
2026-10-03

DRAWN
Amish Chadha

MATERIAL / NOTES
SHS 40 x 40 x 3 and 4 mm; SHS 30 x 30 x 3 mm; 2 mm sheet; 6, 8, 10 mm plate; S275
Licensed CERN-OHL-S-2.0 · Design Molecule Lab · designmolecule.com | Generated from cad/src; do not edit by hand

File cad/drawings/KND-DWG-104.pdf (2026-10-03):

### BUILD PLAN SKETCH, PLAN NOT YET BUILT KilnDeck · github.com/BoujeeEnjinia1701/kilndeck

FRONT VIEW
Scale 1:10; looking at the front (along +Y)

TOP VIEW
Scale 1:10; looking down (along -Z)

RIGHT VIEW
Scale 1:10; looking at the right side (along -X)

1080

260 80

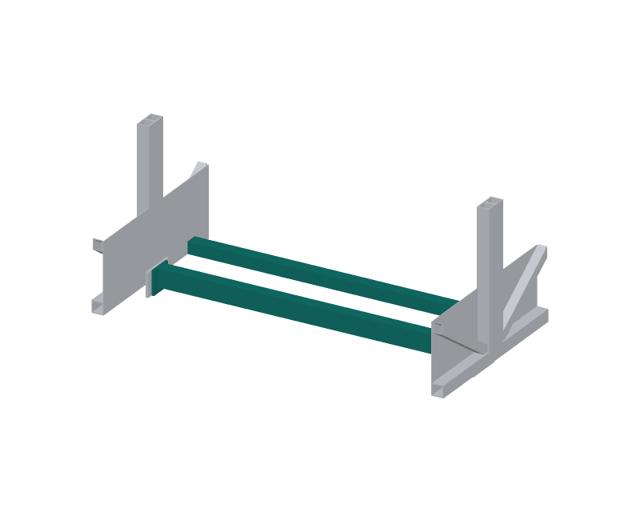
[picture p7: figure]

WHERE IT GOES
This part in colour, its neighbours in grey

HOW TO MAKE IT AND HOW IT FITS
Frame bearer (back in the sketch): RHS 60 x 40 x 4, 1,048 mm, with an 8 x 80 x 80 mm end plate welded on each end: overall 1,064 mm. Four 13 mm holes per end plate, 20 mm in from each edge; they match the cleats on the trusses. M12 grade 8.8 bolts.
The frame bearers sit at both deck ends and at the three splices, and make each pair of verticals and the floor a stiff U-frame. Panel bearer (front): SHS 40 x 40 x 3, 1,080 mm, top flush with the chord tops; held by 50 x 50 x 5 angle cleats and 2 x M10 each end. Hangers for the line shaft: 6 mm plate under each frame bearer, 380 mm right of the middle (see the drive sketch).
Check: tops of all bearers level with the chord tops within 1 mm.
REV | DESCRIPTION | DATE | BY
P1 | Making sketch for the prototype build plan | 2026-10-03 | AC
KILNDECK | github.com/BoujeeEnjinia1701/kilndeck

## KilnDeck frame bearer (make 5) and panel bearer (make 4): making sketch

DRAWING NO.
KND-DWG-104

REV
P1

SHEET
1 of 1

SIZE

## ANSI B

SCALE
1:10

UNITS
mm
PROJECTION | DATE
2026-10-03

DRAWN
Amish Chadha

MATERIAL / NOTES
RHS 60 x 40 x 4 mm; SHS 40 x 40 x 3 mm; 8 mm plate; S275
Licensed CERN-OHL-S-2.0 · Design Molecule Lab · designmolecule.com | Generated from cad/src; do not edit by hand

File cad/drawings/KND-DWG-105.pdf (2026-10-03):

### BUILD PLAN SKETCH, PLAN NOT YET BUILT KilnDeck · github.com/BoujeeEnjinia1701/kilndeck

FRONT VIEW
Scale 1:10; looking at the front (along +Y)

TOP VIEW
Scale 1:10; looking down (along -Z)

RIGHT VIEW
Scale 1:10; looking at the right side (along -X)

1070

858 43

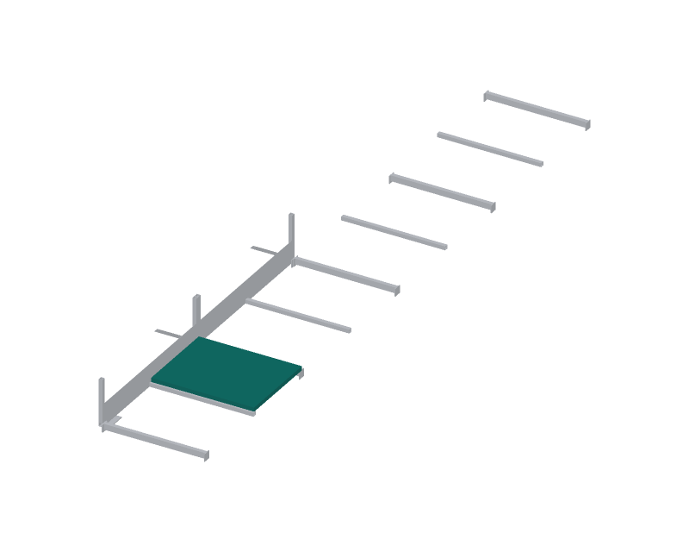
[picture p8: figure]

WHERE IT GOES
This part in colour, its neighbours in grey

HOW TO MAKE IT AND HOW IT FITS
Make eight, 1,070 mm across the deck by about 858 mm (end panels 818 mm). Panel 1 at the gate end has a 86 x 46 mm notch for the hand wheel chain case.
Frame: 40 x 40 x 4 angle welded into a rectangle, legs inward. Underside: 1 mm aluminium sheet riveted under the frame, bright side down, to reflect heat from the crust. Do not paint it.
Board: 37 mm calcium silicate cut to fit inside the frame, dry.
Top: 2 mm steel sheet stitch welded to the frame, light grey anti-slip coating. Drill two 10 mm drain holes at the low corner. Fit: rests on two bearers, 2 mm gap to the next panel and 5 mm to the toe boards; two M8 bolts each end into the bearers.
Check: about 30 kg; flat within 3 mm; no gap in the board.
REV | DESCRIPTION | DATE | BY
P1 | Making sketch for the prototype build plan | 2026-10-03 | AC
KILNDECK | github.com/BoujeeEnjinia1701/kilndeck

## KilnDeck insulated floor panel (make 8): making sketch

DRAWING NO.
KND-DWG-105

REV
P1

SHEET
1 of 1

SIZE

## ANSI B

SCALE
1:10

UNITS
mm
PROJECTION | DATE
2026-10-03

DRAWN
Amish Chadha

MATERIAL / NOTES
40 x 40 x 4 angle; 2 mm steel sheet; 37 mm calcium silicate board; 1 mm aluminium
Licensed CERN-OHL-S-2.0 · Design Molecule Lab · designmolecule.com | Generated from cad/src; do not edit by hand

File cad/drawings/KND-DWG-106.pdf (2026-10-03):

### BUILD PLAN SKETCH, PLAN NOT YET BUILT KilnDeck · github.com/BoujeeEnjinia1701/kilndeck

FRONT VIEW
Scale 1:10; looking at the front (along +Y)

TOP VIEW
Scale 1:10; looking down (along -Z)

RIGHT VIEW
Scale 1:10; looking at the right side (along -X)

1080

40 1143

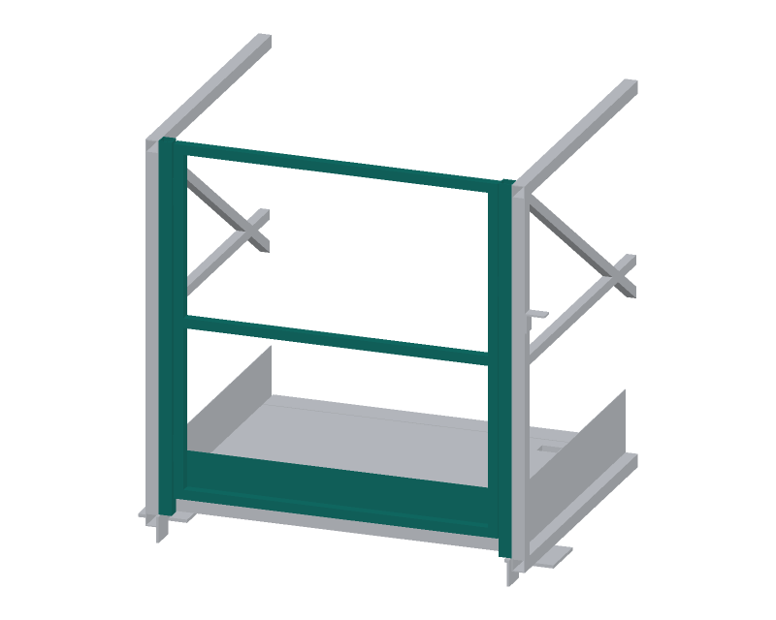
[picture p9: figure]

WHERE IT GOES
This part in colour, its neighbours in grey

HOW TO MAKE IT AND HOW IT FITS
Posts: SHS 40 x 40 x 3, 1,143 mm, one bolted to the inside of each truss end vertical with three M12 bolts.
Gate leaf (drawn): 30 x 30 x 3 frame 1,070 x 1,075 mm, knee rail at 550 mm above the floor, 2 mm toe plate 150 mm tall, 5 mm clear of each post and 10 mm above the floor.
Hinges: two self-closing spring hinges on the side A post; the gate opens inward onto the deck only, never out over the drop.
Latch: gravity latch on the side B post at 750 mm above the floor. Inner end rail: same posts with a fixed top rail, knee rail and toe plate, all welded, bolted to the inner end verticals.
Check: gate closes and latches by itself from 90 degrees open.
REV | DESCRIPTION | DATE | BY
P1 | Making sketch for the prototype build plan | 2026-10-03 | AC
KILNDECK | github.com/BoujeeEnjinia1701/kilndeck

## KilnDeck outer end gate and inner end rail: making sketch

DRAWING NO.
KND-DWG-106

REV
P1

SHEET
1 of 1

SIZE

## ANSI B

SCALE
1:10

UNITS
mm
PROJECTION | DATE
2026-10-03

DRAWN
Amish Chadha

MATERIAL / NOTES
SHS 40 x 40 x 3 and 30 x 30 x 3 mm; 2 mm sheet; spring hinges; S275
Licensed CERN-OHL-S-2.0 · Design Molecule Lab · designmolecule.com | Generated from cad/src; do not edit by hand

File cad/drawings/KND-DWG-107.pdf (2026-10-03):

### BUILD PLAN SKETCH, PLAN NOT YET BUILT KilnDeck · github.com/BoujeeEnjinia1701/kilndeck

FRONT VIEW
Scale 1:20; looking at the front (along +Y)

TOP VIEW
Scale 1:20; looking down (along -Z)

RIGHT VIEW
Scale 1:20; looking at the right side (along -X)

320

171 1203

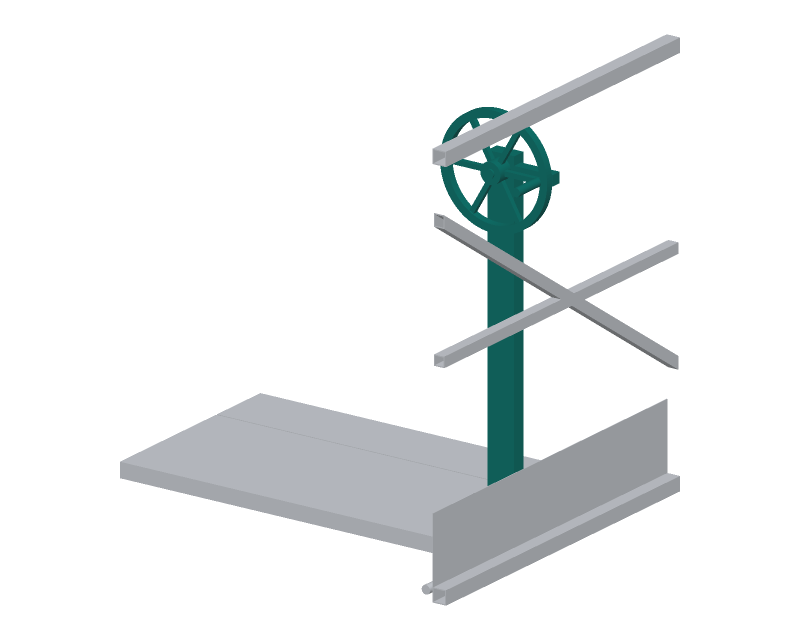
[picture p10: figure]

WHERE IT GOES
This part in colour, its neighbours in grey

HOW TO MAKE IT AND HOW IT FITS
Chain case: 2 mm sheet box 80 x 40 mm, from 210 mm above the wall top to 40 mm over the hand wheel shaft; bolts to the frame bearer
below and through the floor notch. Seal the seams.
Hand wheel: bought 320 mm wheel with a 12-hole rim (drill 11 mm holes on a 298 mm circle if it has none), on a 25 mm shaft in two flange bearings on the case, 860 mm above the floor.
Chain: 08B-1, 15-tooth sprockets on the hand wheel shaft and on the line shaft, 1:1, tensioned by slotting the upper bearings.
Line shaft: 25 mm bright bar in three lengths with two couplings, five pillow blocks on 6 mm hangers under the frame bearers,
through the trucks to a sprocket and chain on each drive wheel.
Lock pin: spring plunger on the case; it drops into a rim hole.
Check: one turn moves the deck about 283 mm; both ends move together.
REV | DESCRIPTION | DATE | BY
P1 | Making sketch for the prototype build plan | 2026-10-03 | AC
KILNDECK | github.com/BoujeeEnjinia1701/kilndeck

## KilnDeck travel drive: hand wheel, chain case and lock pin: making sketch

DRAWING NO.
KND-DWG-107

REV
P1

SHEET
1 of 1

SIZE

## ANSI B

SCALE
1:20

UNITS
mm
PROJECTION | DATE
2026-10-03

DRAWN
Amish Chadha

MATERIAL / NOTES
320 mm hand wheel; 2 mm sheet; 25 mm bar; ISO 08B-1 chain
Licensed CERN-OHL-S-2.0 · Design Molecule Lab · designmolecule.com | Generated from cad/src; do not edit by hand

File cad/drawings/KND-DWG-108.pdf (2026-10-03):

### BUILD PLAN SKETCH, PLAN NOT YET BUILT KilnDeck · github.com/BoujeeEnjinia1701/kilndeck

FRONT VIEW
Scale 1:20; looking at the front (along +Y)

TOP VIEW
Scale 1:20; looking down (along -Z)

RIGHT VIEW
Scale 1:20; looking at the right side (along -X)

40

1729 80

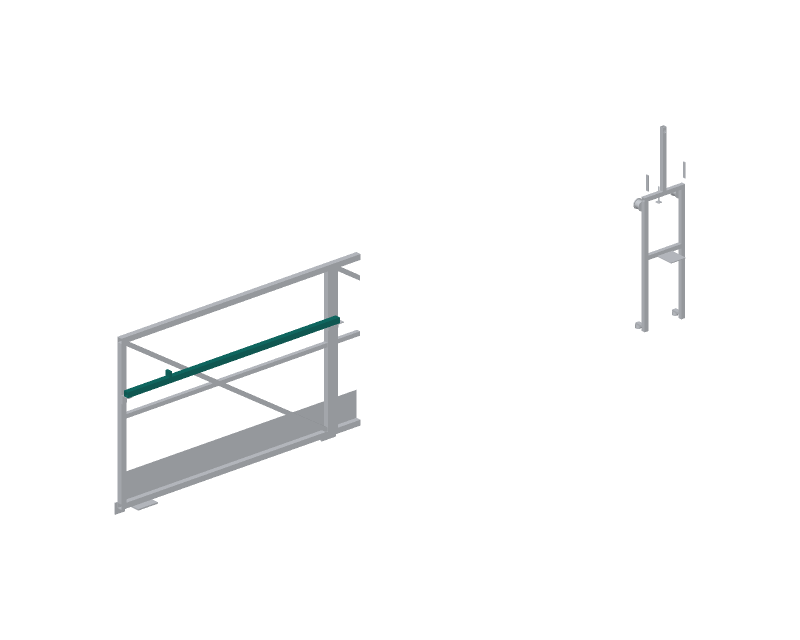
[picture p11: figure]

WHERE IT GOES
This part in colour, its neighbours in grey

HOW TO MAKE IT AND HOW IT FITS
Make four, one per side B truss module, 1,723 mm long.
It sits on the shelf brackets of the module's end verticals, 20 mm out from them, top 750 mm above the floor; two M10 bolts down through each bracket.
Joints over the splices: ends square and flush within 0.5 mm so the carriage wheels roll across without a step.
End stops: a 40 x 40 x 20 mm block welded on top, 3,090 mm each side of the deck middle (end modules only).
Check: rail straight and level within 2 mm over the deck.
REV | DESCRIPTION | DATE | BY
P1 | Making sketch for the prototype build plan | 2026-10-03 | AC
KILNDECK | github.com/BoujeeEnjinia1701/kilndeck

## KilnDeck carriage rail (make 4): making sketch

DRAWING NO.
KND-DWG-108

REV
P1

SHEET
1 of 1

SIZE

## ANSI B

SCALE
1:20

UNITS
mm
PROJECTION | DATE
2026-10-03

DRAWN
Amish Chadha

MATERIAL / NOTES
SHS 40 x 40 x 3 mm; 20 x 40 x 40 mm block; S275
Licensed CERN-OHL-S-2.0 · Design Molecule Lab · designmolecule.com | Generated from cad/src; do not edit by hand

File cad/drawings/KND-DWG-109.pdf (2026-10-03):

### BUILD PLAN SKETCH, PLAN NOT YET BUILT KilnDeck · github.com/BoujeeEnjinia1701/kilndeck

FRONT VIEW
Scale 1:20; looking at the front (along +Y)

TOP VIEW
Scale 1:20; looking down (along -Z)

RIGHT VIEW
Scale 1:20; looking at the right side (along -X)

231

372 1365

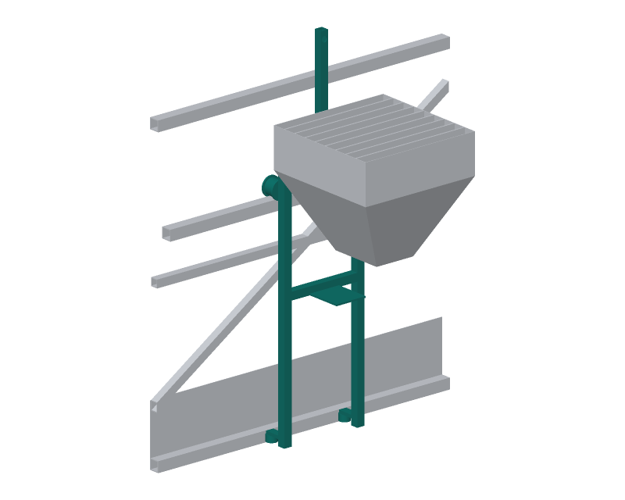
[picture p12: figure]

WHERE IT GOES
This part in colour, its neighbours in grey

HOW TO MAKE IT AND HOW IT FITS
Posts: two SHS 30 x 30 x 3, 300 mm apart, from the chord bottom up to 110 mm above the carriage rail; tied by two cross members.
Top wheels: 60 mm double-flanged, 40 mm tread, on 20 mm stub axles welded into the posts; they ride on top of the carriage rail.
Guide rollers: 40 mm ball-bearing rollers on vertical pins, on arms from the post feet; they bear on the outer face of the bottom
chord and stop the hopper's weight swinging the frame in.
Crank post: SHS 30 x 30 x 3 up to 30 mm over the crank shaft; 21 mm bearing hole at 1,260 mm above the floor.
Hopper brackets: 6 mm plates from each post to the hopper wall. Housing shelf: 6 x 120 mm plate under the rotor housing.
Clamp: M12 screw with a pad that clamps the frame to the rail. Check: rolls the full rail with 2 to 5 mm play at the rollers.
REV | DESCRIPTION | DATE | BY
P1 | Making sketch for the prototype build plan | 2026-10-03 | AC
KILNDECK | github.com/BoujeeEnjinia1701/kilndeck

## KilnDeck hopper carriage frame: making sketch

DRAWING NO.
KND-DWG-109

REV
P1

SHEET
1 of 1

SIZE

## ANSI B

SCALE
1:20

UNITS
mm
PROJECTION | DATE
2026-10-03

DRAWN
Amish Chadha

MATERIAL / NOTES
SHS 30 x 30 x 3 mm; 6 mm plate; 60 mm wheels; 40 mm rollers; S275
Licensed CERN-OHL-S-2.0 · Design Molecule Lab · designmolecule.com | Generated from cad/src; do not edit by hand

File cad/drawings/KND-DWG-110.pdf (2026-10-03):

### BUILD PLAN SKETCH, PLAN NOT YET BUILT KilnDeck · github.com/BoujeeEnjinia1701/kilndeck

FRONT VIEW
Scale 1:10; looking at the front (along +Y)

TOP VIEW
Scale 1:10; looking down (along -Z)

RIGHT VIEW
Scale 1:10; looking at the right side (along -X)

450

450 420

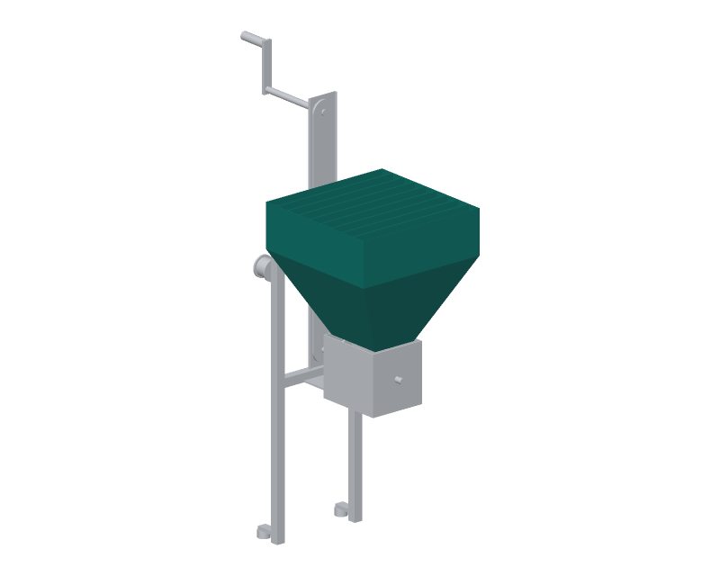
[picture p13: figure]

WHERE IT GOES
This part in colour, its neighbours in grey

HOW TO MAKE IT AND HOW IT FITS
About 52 litres. Top 450 x 450 mm; 150 mm straight sides; then a 270 mm taper to a 200 x 150 mm outlet over the rotor housing. Cut four tapered side panels and four straight panels from 2 mm sheet; weld the seams outside and grind smooth inside so wet coal does not hang up.
Grille: 6 mm flat bars across the top at 50 mm pitch, 25 mm deep, welded at both ends; lumps over about 44 mm stay on top.
Fit: the outlet welds to the top of the rotor housing; two 6 mm brackets bolt it to the carriage posts.
Check: fill with 52 L of water before fitting; no leaks.
REV | DESCRIPTION | DATE | BY
P1 | Making sketch for the prototype build plan | 2026-10-03 | AC
KILNDECK | github.com/BoujeeEnjinia1701/kilndeck

## KilnDeck fuel hopper: making sketch

DRAWING NO.
KND-DWG-110

REV
P1

SHEET
1 of 1

SIZE

## ANSI B

SCALE
1:10

UNITS
mm
PROJECTION | DATE
2026-10-03

DRAWN
Amish Chadha

MATERIAL / NOTES
2 mm steel sheet; 6 mm flat bar grille; S275
Licensed CERN-OHL-S-2.0 · Design Molecule Lab · designmolecule.com | Generated from cad/src; do not edit by hand

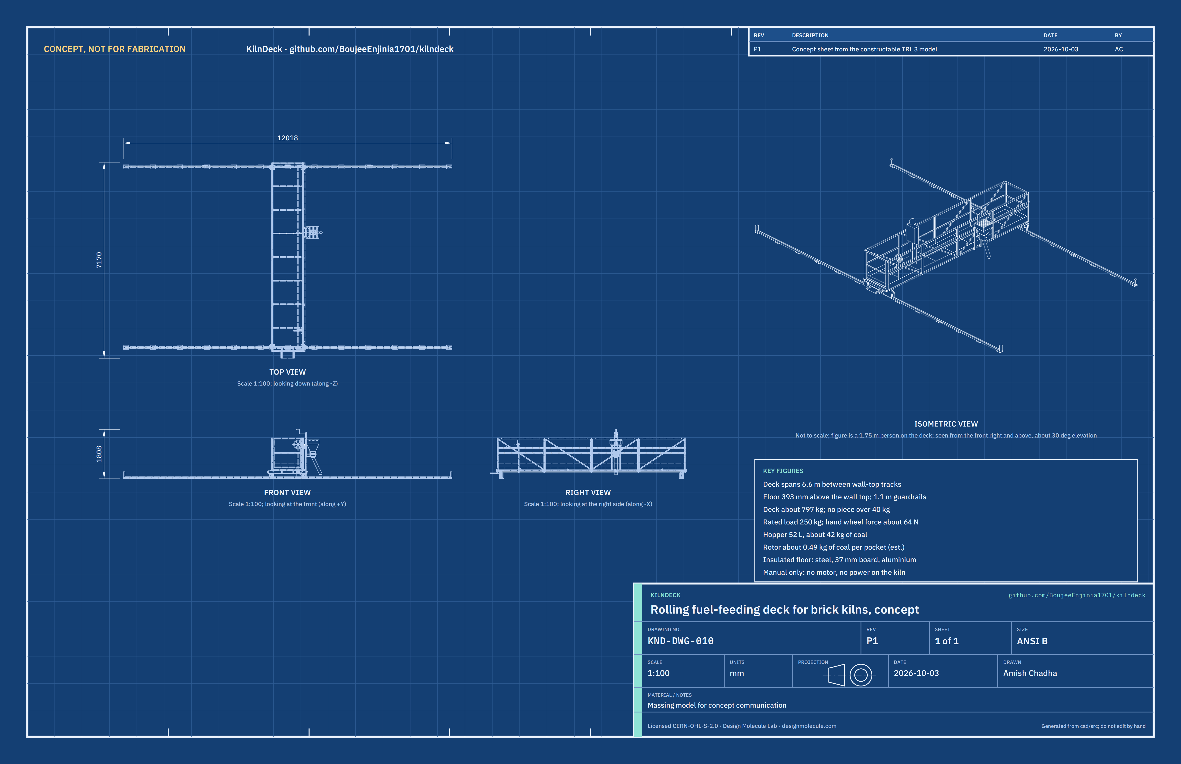
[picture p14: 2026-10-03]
media/concept-blueprint.png

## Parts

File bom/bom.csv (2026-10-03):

item | qty | spec | supplier | unit_cost_usd | make_buy | notes
1 Levelling pads | 26 | 200 x 150 x 10 mm steel plate, S275, with 1 and 2 mm steel shims; laid on a thin lime-sand bed every 1.0 m along each wall top; about 2.4 kg each | Local steel stockist | 3.50 | make | Model mass x USD 1.30/kg plus shims; KND-DDR-002
2 Track modules with fishplates | 8 | UPN 80 channel 3,000 mm lying flanges down with a 20 mm round bar welded along the web centre as the rail; 6 x 30 x 200 mm fishplates with slotted holes and 2 x M12 bolts at each joint; 6 mm expansion gap; S275; about 33 kg each | Local steel stockist | 46.00 | make | Model mass x USD 1.30/kg plus fishplates and bolts; four per wall for a 12 m demonstration run
3 Track end stops | 4 | Welded box of 8 mm plate 60 x 80 x 200 mm bolted through the channel web with 2 x M12 at each end of each track; rubber face; about 7.5 kg each | Local steel stockist | 12.00 | make | Model mass x USD 1.30/kg plus bolts
4 End trucks | 2 | RHS 100 x 50 x 4 mm, 1,400 mm long, with 8 mm wheel fork plates, 10 mm seat plates for the truss feet, 6 mm derailment guards either side of the track, two rubber buffers and a 32 mm hole for the line shaft; the outer truck also carries a 4 mm chequer plate boarding step; about 38 kg (outer) and 26 kg (inner) | Local steel stockist; rubber buffers from a hardware store | 58.00 | make | Average of USD 66 (outer) and USD 50 (inner); KND-DDR-002
5 Track wheels | 4 | 100 mm U-groove steel wheel with sealed ball bearings and a 20 mm axle, rated at least 500 kg; 24 mm groove for the two outer-wall wheels, 44 mm groove for the two inner-wall wheels; two axles long enough to carry a drive sprocket | Sliding gate hardware supplier | 30.00 | buy | Regional retail estimate for a heavy-duty gate wheel; worst wheel load about 450 kg (KND-CAL-001)
6 Side truss modules | 8 | Welded truss 1,725 mm long and 1,183 mm tall: SHS 40 x 40 x 3 bottom chord and top chord (the top rail), SHS 40 x 40 x 4 end verticals, SHS 30 x 30 x 3 diagonal and knee rail, 2 mm toe board, 8 mm bearer cleats; side B modules carry two carriage rail brackets; end modules carry a 10 mm foot plate; 6 x M12 bolts per splice; S275; about 37 to 39 kg each | Local steel stockist | 54.00 | make | Model mass x USD 1.30/kg plus splice bolts; KND-DDR-002
7 Cross bearers | 9 | Five frame bearers RHS 60 x 40 x 4 mm with 8 mm end plates bolted to the cleats with 4 x M12 (moment joints at the ends and splices) and four panel bearers SHS 40 x 40 x 3 mm with 2 x M10; 1,064 mm long; S275 | Local steel stockist | 10.33 | make | 5 x USD 13 plus 4 x USD 7, averaged
8 Insulated floor panels | 8 | About 860 x 1,070 mm: 40 x 40 x 4 angle edge frame, 2 mm steel tread sheet with light grey anti-slip coating on top, 37 mm calcium silicate board inside, 1 mm aluminium sheet underneath as a radiation shield; about 30 kg each | Local steel stockist; insulation supplier (calcium silicate); aluminium sheet from a metals trader | 68.00 | make | USD 30 steel + USD 25 board + USD 10 aluminium + USD 3 coating; board compressive strength to confirm
9 End rail and gate | 1 | Inner end rail: two posts, top rail SHS 40 x 40 x 3, knee rail and toe plate, bolted to the truss end verticals. Outer end gate: same posts with a 30 x 30 x 3 gate leaf, two self-closing spring hinges, gravity latch, opening inward onto the deck; about 40 kg together | Local steel stockist; spring hinges and latch from a hardware store | 81.00 | make | USD 25 inner rail + USD 56 gate
10 Travel drive | 1 | 25 mm bright steel line shaft 6.8 m in three lengths with two rigid couplings, five UCP205 pillow blocks on hangers, two end chain drives (ISO 08B-1 chain, 15-tooth sprockets) with 2 mm sheet guards, a 320 mm hand wheel with a 12-hole rim, a sealed chain case down through the floor and a spring lock pin | Bearing and transmission supplier; local steel stockist | 248.00 | make | Shaft USD 42 + couplings USD 16 + blocks USD 50 + chain USD 24 + six sprockets USD 54 + hand wheel USD 35 + case and guards USD 15 + lock pin USD 12
11 Carriage rail with brackets | 1 | Four lengths of SHS 40 x 40 x 3 mm on 6 mm shelf brackets on the side B truss verticals, top 750 mm above the floor; welded end stops at the carriage travel limits | Local steel stockist | 40.00 | make | Model mass x USD 1.30/kg plus bolts
12 Hopper carriage frame | 1 | SHS 30 x 30 x 3 posts, cross members and crank post; two 60 mm double-flanged wheels on the carriage rail; two 40 mm guide rollers on the outer face of the bottom chord; hopper brackets, housing shelf and a screw clamp onto the rail | Local steel stockist; wheels and rollers from a bearing supplier | 46.00 | make | USD 11 steel + USD 18 wheels + USD 12 rollers + USD 5 clamp
13 Fuel hopper | 1 | About 50 litres: 2 mm steel sheet, 450 x 450 mm top, 150 mm straight, tapered 270 mm to a 200 x 150 mm outlet; bar grille across the top at 50 mm pitch; about 14 kg | Local steel stockist | 23.00 | make | Model mass x USD 1.30/kg plus welding
14 Metering rotor housing and crank | 1 | Four-pocket rotor 160 mm diameter, 200 mm long on a 20 mm shaft in two flange bearings, inside a welded 4 mm housing; ISO 08B-1 chain and two sprockets up to a 20 mm crank shaft over the guardrail; 140 mm crank with a handle; sheet chain guard | Local steel stockist; bearing and transmission supplier | 78.00 | make | USD 26 steel + USD 16 bearings + USD 28 chain and sprockets + USD 8 guard and handle
15 Swing spout | 1 | 100 x 3 mm steel tube about 700 mm long, leaning outward 300 mm, welded to a turned collar that swivels under the rotor housing outlet | Local steel stockist; local machine shop (collar) | 20.00 | make | USD 10 steel + USD 10 turning
16 Heat-resistant grip sleeves | 11 | Silicone rubber sleeve for a 40 mm square top rail, 3 mm wall, rated to 200 C; sold by the metre | Industrial rubber supplier | 9.00 | buy | Regional estimate per metre; between the verticals on both top rails
17 Fasteners paint and consumables | 1 | M10 and M12 grade 8.8 bolts, nuts and washers for every joint; E6013 electrodes; zinc primer and heat-resistant topcoat; cutting discs | Hardware store | 180.00 | buy | Not modelled; regional estimate

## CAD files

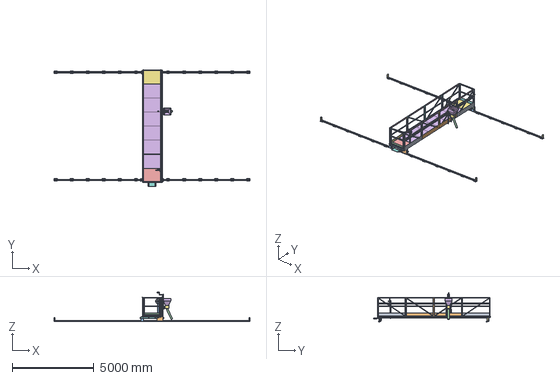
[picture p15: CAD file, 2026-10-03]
cad/step/kilndeck-assembly.step
12018.0 x 7170.0 x 1808.0 mm

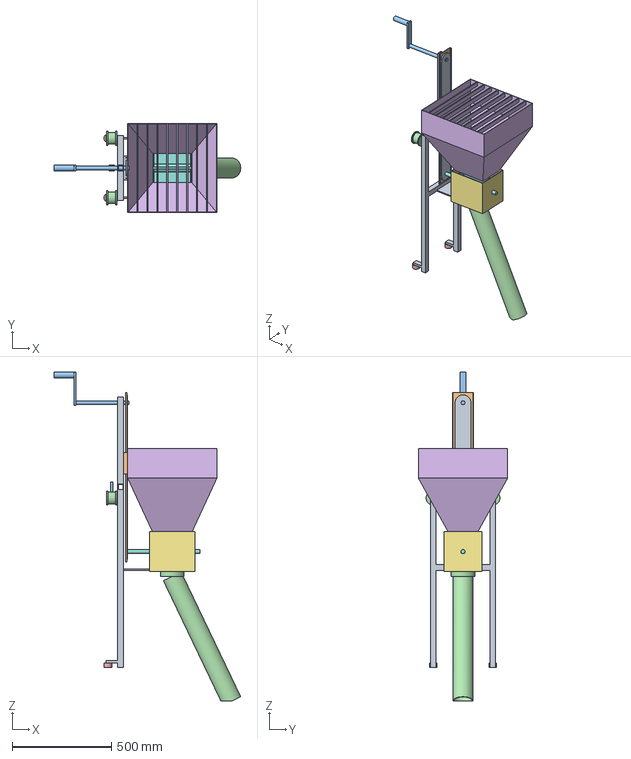
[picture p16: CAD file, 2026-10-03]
cad/step/kilndeck-carriage.step
940.1 x 450.0 x 1658.0 mm

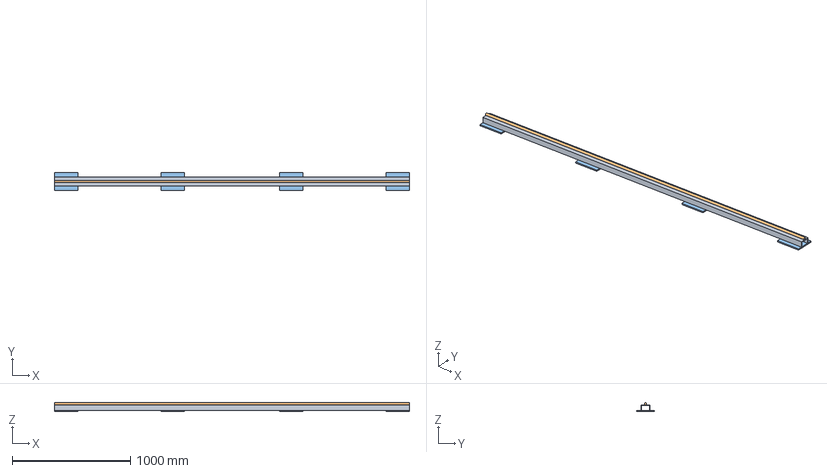
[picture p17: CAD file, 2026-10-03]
cad/step/kilndeck-track-module.step
3000.0 x 150.0 x 75.0 mm

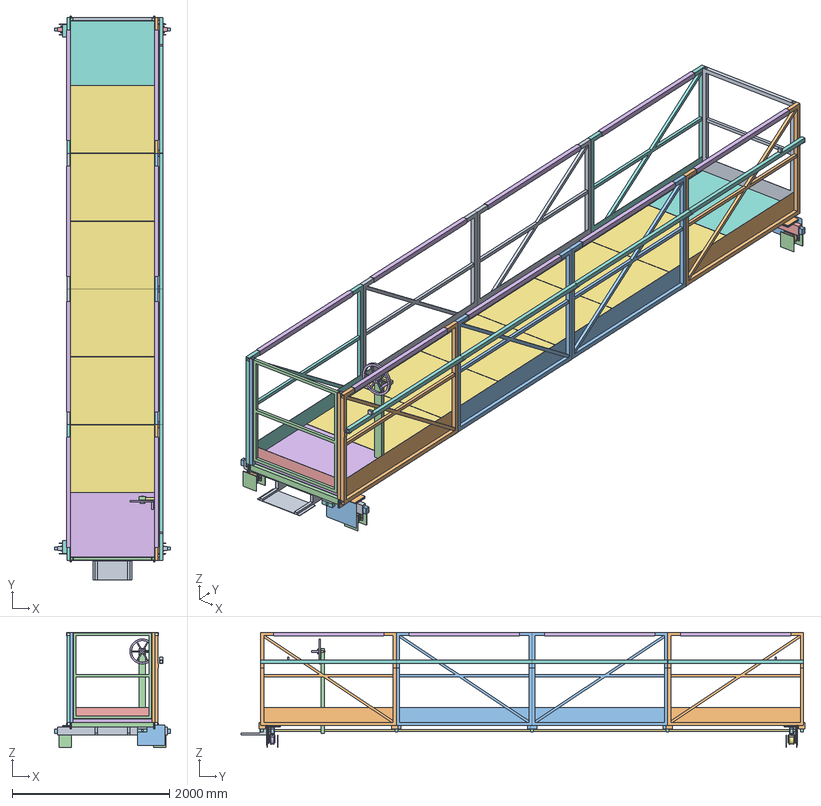
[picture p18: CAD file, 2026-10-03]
cad/step/kilndeck-deck.step
1480.0 x 7170.0 x 1466.0 mm

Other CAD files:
cad/stl/kilndeck-carriage.stl
cad/stl/kilndeck-deck.stl
cad/stl/kilndeck-track-module.stl

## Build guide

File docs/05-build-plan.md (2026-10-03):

---
doc_id: KND-BLD-001
title: KilnDeck prototype build plan
project: KilnDeck
doc_type: Build plan
version: "0.1"
status: Draft
date: '2026-10-03'
author: Amish Chadha
license: CERN-OHL-S-2.0
revisions:
- version: "0.1"
  date: '2026-10-03'
  author: Amish Chadha
  change: First build plan; design made constructable (KND-DDR-002)
---

# KilnDeck prototype build plan

**Plan, not yet built.** How to build the first proof-of-concept prototype, component by component. Building and testing to it is TRL 4 work. Decisions and items to confirm are kept in the design decisions register ([docs/06-design-decisions.md](06-design-decisions.md)), not here.

## 1. What you are building

Figure 1. Every component, pulled apart and numbered in build order

*Figure 1. Every component pulled apart and numbered in build order.*

The prototype is a walkway deck 6.9 m long that spans the trench of a bull's trench brick kiln and rolls along the kiln on two tracks, one on each wall top, so the fireman can feed fuel without standing on the crust. Figure 1 shows the 22 groups of parts in the order you make or fit them: 12 m of track on each wall, two end trucks on four wheels, two side trusses that are also the guardrails, bearers and eight insulated floor panels, an end rail and a gate, a hand-wheel travel drive, and a hopper carriage with its metering rotor and swing spout. Almost everything is cut, drilled and stick welded from stock steel hollow section, channel and plate; the wheels, bearings, chains, sprockets, hand wheel, insulation board and grip sleeves are bought. Every piece is bolted together on the kiln, and none weighs more than 40 kg. The parts cost about USD 2,627 from the bill of materials.

> **Safety:** KilnDeck carries a person over a burning kiln, and its drive and rotor have pinch points. The build involves stick welding, grinding, carrying 40 kg pieces up the kiln and working at the edge of the kiln walls. Assemble the deck only over the cold zone of the kiln (where bricks are being set or drawn and there is no fire beneath), never over the fire. No one stands on the deck over a fire until the safety stops in section 6 are cleared; that is TRL 4 work and on hold.

## 2. What changed to make it buildable

The concept showed what the deck does; its parts had no sections, joints or fixings. Each change keeps what the deck does and is recorded in decision record KND-DDR-002, decided by Amish under his pre-approval of 2026-10-03.

*Table 1. Changes from the concept.*

| Component | The concept had | The buildable design has | Why |
| --- | --- | --- | --- |
| Track | Rails on supports | 3 m channel modules with a round bar rail, on levelling pads, joined by slotted fishplates (Figure 3) | Stock steel, 33 kg pieces, joints that slide as the track heats |
| Track ends | Nothing | Bolted end stops with rubber faces | The deck must not run off a track |
| End trucks and wheels | Flanged wheels | Box-section trucks with derailment guards; U-groove wheels, the inner pair with a wide groove (Figure 5) | A lifted wheel lands on the guards, never the crust; the deck can grow with heat |
| Deck and guardrail | A platform and a separate rail | Two bolted side trusses whose top chords are the 1.1 m top rails (Figure 6) | Spans 6.6 m and keeps every piece under 40 kg |
| Stiff posts | Not defined | Frame bearers bolted to cleats at the ends and splices (Figure 8) | A push on the top rail is carried into the floor |
| Floor | Insulated floor | Bolted panels: steel tread, calcium silicate board, aluminium underside (Figure 10) | 30 kg each; the bright underside reflects crust heat |
| Moving and holding the deck | Pushed by hand; a separate brake | Hand wheel and line shaft driving one wheel at each end; a lock pin in the hand wheel (Figures 13 and 14) | Both ends move together; one pin holds the deck |
| Hopper | On the deck | On a carriage along the outside of truss B (Figure 16) | The floor stays whole; one hopper serves the whole row |
| Rotor | Turned at the hopper | Chain up to a crank above the guardrail (Figure 19) | Turned from inside the rail |
| Assembly | Not worked out | Assembled over the cold zone on trestles, in the order of section 4 | No one works over the fire |

## 3. Making the components

Make and check each component before the assembly step that needs it. Sizes are in millimetres. "Outer" is the end of the deck on the outer kiln wall, where the gate is; "inner" is the inner wall. "Side A" is the left-hand truss seen from the gate, "side B" the right-hand truss, which carries the hopper. Workshop tolerance is 1 mm unless a step says otherwise. Weld with 3.2 mm E6013 electrodes; fillets are 4 mm unless stated. Paint all steel with zinc primer and a heat-resistant topcoat, except the bright underside of the floor panels. Mark every piece with its name and position in paint marker.

### 3.1 Track modules, levelling pads and end stops

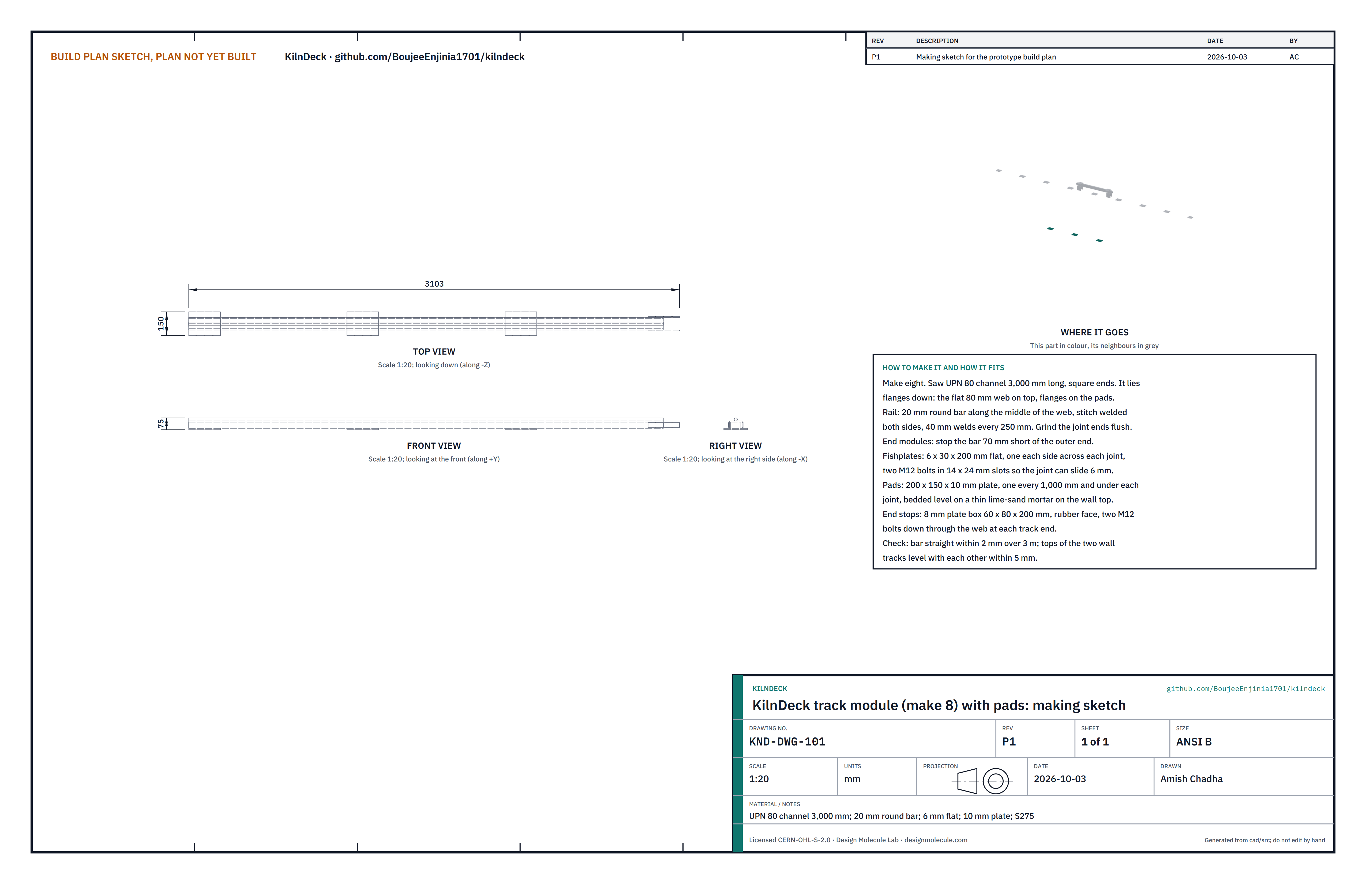
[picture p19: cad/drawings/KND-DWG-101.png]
Figure 2. Making sketch of the track module


*Figure 2. Track module making sketch (KND-DWG-101).*

**What it is and what it is made from.** The two tracks the deck runs on, one on each wall top, in four 3 m modules per wall for the 12 m demonstration run. UPN 80 steel channel, S275; 20 mm round bar; 6 x 30 mm flat bar for fishplates; 10 mm plate for 26 levelling pads; 8 mm plate for four end stops.

**How to make it.**

1. Saw eight 3,000 mm lengths of channel with square ends; deburr.
2. Lay each one flanges down, so the flat 80 mm web is on top.
3. Lay the 20 mm bar along the middle of the web and stitch weld both sides, 40 mm welds every 250 mm. On the four end modules, stop the bar 70 mm short of the outer end.
4. Cut 12 fishplates 6 x 30 x 200 mm and slot each with two 14 x 24 mm slots, 100 mm apart. Drill matching 13 mm holes in both flanges 50 mm from each module end.
5. Cut 26 pads 200 x 150 x 10 mm, plus a few 1 and 2 mm shims of the same size.
6. Make four end stops: a box of 8 mm plate 60 x 80 x 200 mm, with a 10 mm rubber pad bonded to the face the truck meets and two 13 mm holes in its foot that match holes in the channel web.

**How it fits the parts next to it.** Each module lies on pads under its flanges, one pad every 1,000 mm and one under every joint. Two modules meet over a pad with a 6 mm gap; a fishplate each side, bolted through the slots, lets the joint slide as the track heats (Figure 3). The stops bolt down through the web at each track end.

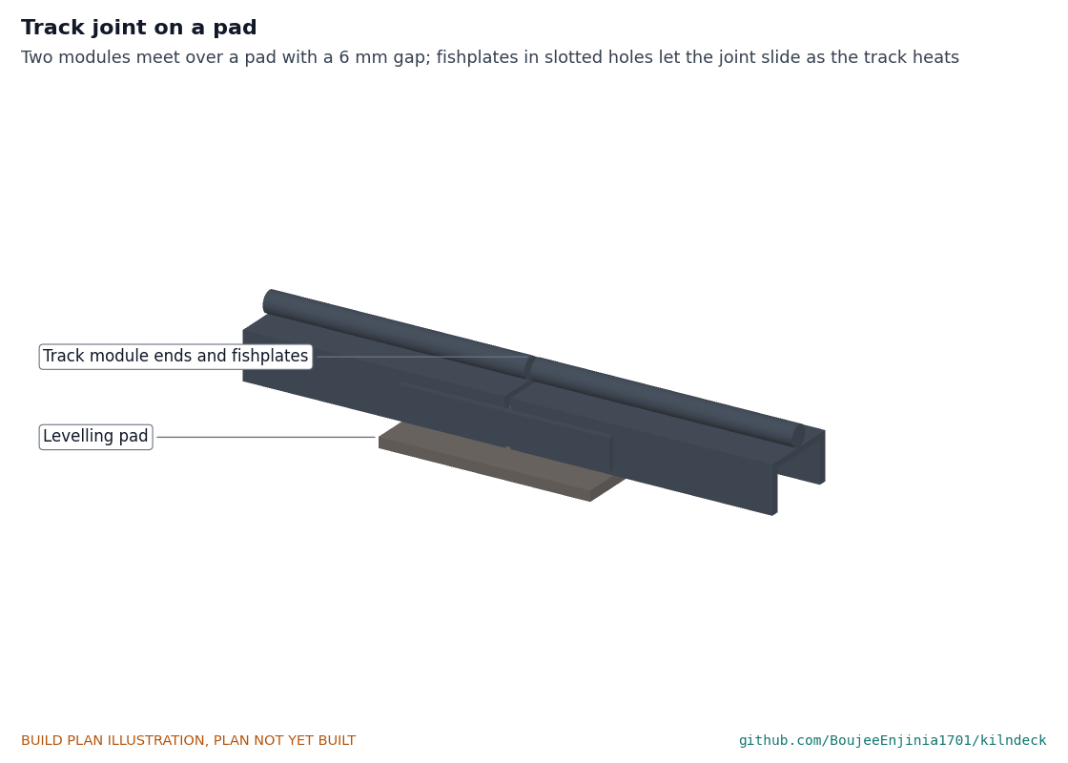
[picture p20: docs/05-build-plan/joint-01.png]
Figure 3. Track joint on a pad


*Figure 3. Track joint on a pad, with fishplates.*

**Check before moving on.** Each bar is straight within 2 mm over 3 m. The fishplate bolts slide in their slots when finger tight.

### 3.2 End trucks

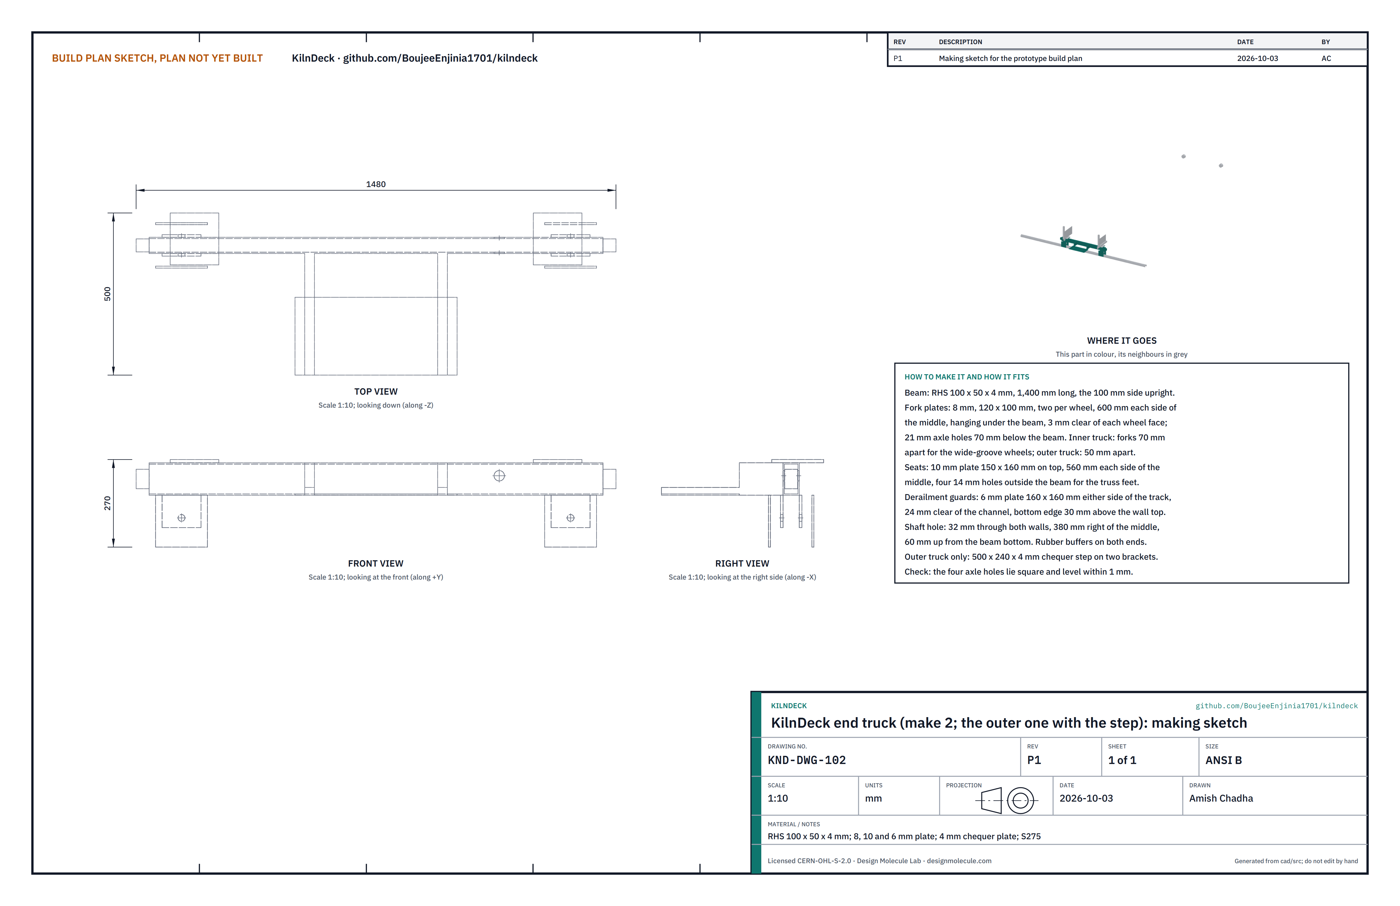
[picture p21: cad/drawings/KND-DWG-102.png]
Figure 4. Making sketch of the end truck


*Figure 4. End truck making sketch (KND-DWG-102).*

**What it is and what it is made from.** The two cross beams that carry the deck's ends on the tracks. RHS 100 x 50 x 4 mm, 1,400 mm long each, the 100 mm side upright; 8 mm plate for the wheel forks; 10 mm plate for the seats; 6 mm plate for the derailment guards; rubber buffers; for the outer truck, 4 mm chequer plate and flat bar for the boarding step.

**How to make it.**

1. Saw two 1,400 mm lengths of RHS. Drill a 32 mm hole through both walls of each, 380 mm to side B of the middle and 60 mm up from the bottom, for the line shaft.
2. Fork plates: eight per truck, 120 x 100 mm, two per wheel at 600 mm each side of the middle, hanging under the beam. Drill a 21 mm axle hole in each, 70 mm below the beam. On the outer truck the plates of each pair are 50 mm apart inside (for 44 mm wheels); on the inner truck, 70 mm (for 64 mm wheels). Weld them square with a 20 mm bar through both pairs of holes.
3. Seats: two 10 mm plates 150 x 160 mm welded on top, centred 560 mm each side of the middle, overhanging the beam toward the deck. Drill four 14 mm holes in each, outside the beam.
4. Derailment guards: four 6 mm plates 160 x 160 mm per truck, one each side of the track at each wheel, 24 mm clear of the channel sides, bottom edge 30 mm above the wall top.
5. Buffers: a rubber block 60 x 40 x 40 mm bolted to each end of the beam.
6. Outer truck only: a 500 x 240 mm step of 4 mm chequer plate on two flat-bar brackets on the outer face, about 200 mm above the wall top.

**How it fits the parts next to it.** The wheels hang in the forks on their axles; the groove of each wheel sits on the round bar, and the guards straddle the track channel (Figure 5). The truss foot plates sit on the seats and bolt through them with four M12 bolts (Figure 7).

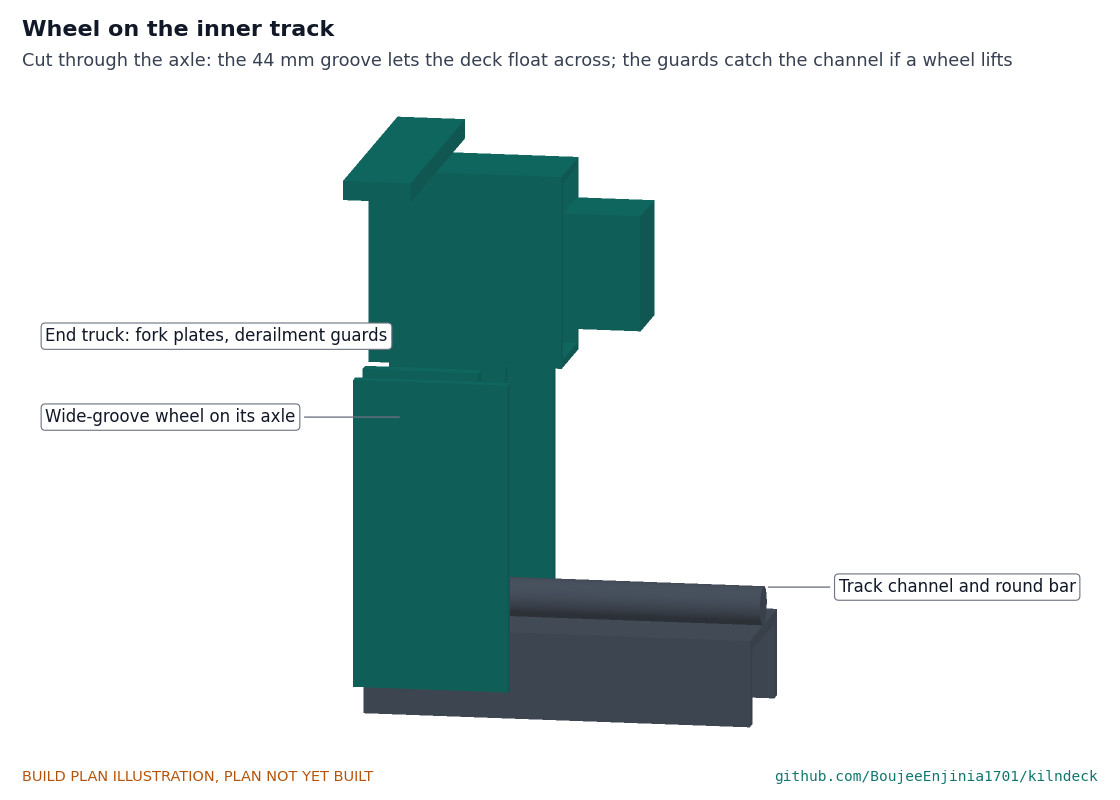
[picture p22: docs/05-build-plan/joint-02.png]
Figure 5. Wheel on the inner track


*Figure 5. Wheel on the inner track, cut through the axle.*

**Check before moving on.** The four axle holes of each truck lie square to the beam and level within 1 mm; a 20 mm bar slides through each pair.

### 3.3 Track wheels (bought)

Buy four 100 mm steel U-groove wheels with sealed ball bearings, each rated at least 500 kg, on 20 mm axles: two with a 24 mm groove for the outer track (these guide the deck) and two with a 44 mm groove for the inner track (these let the deck float about 12 mm either way across the trench). The two wheels on side B are driven, so their axles must be long enough to reach 32 mm past the outside of the fork for a sprocket; have a 5 mm keyway cut in that end. Check that each wheel turns freely and that its groove sits on a length of the 20 mm bar.

### 3.4 Side truss modules

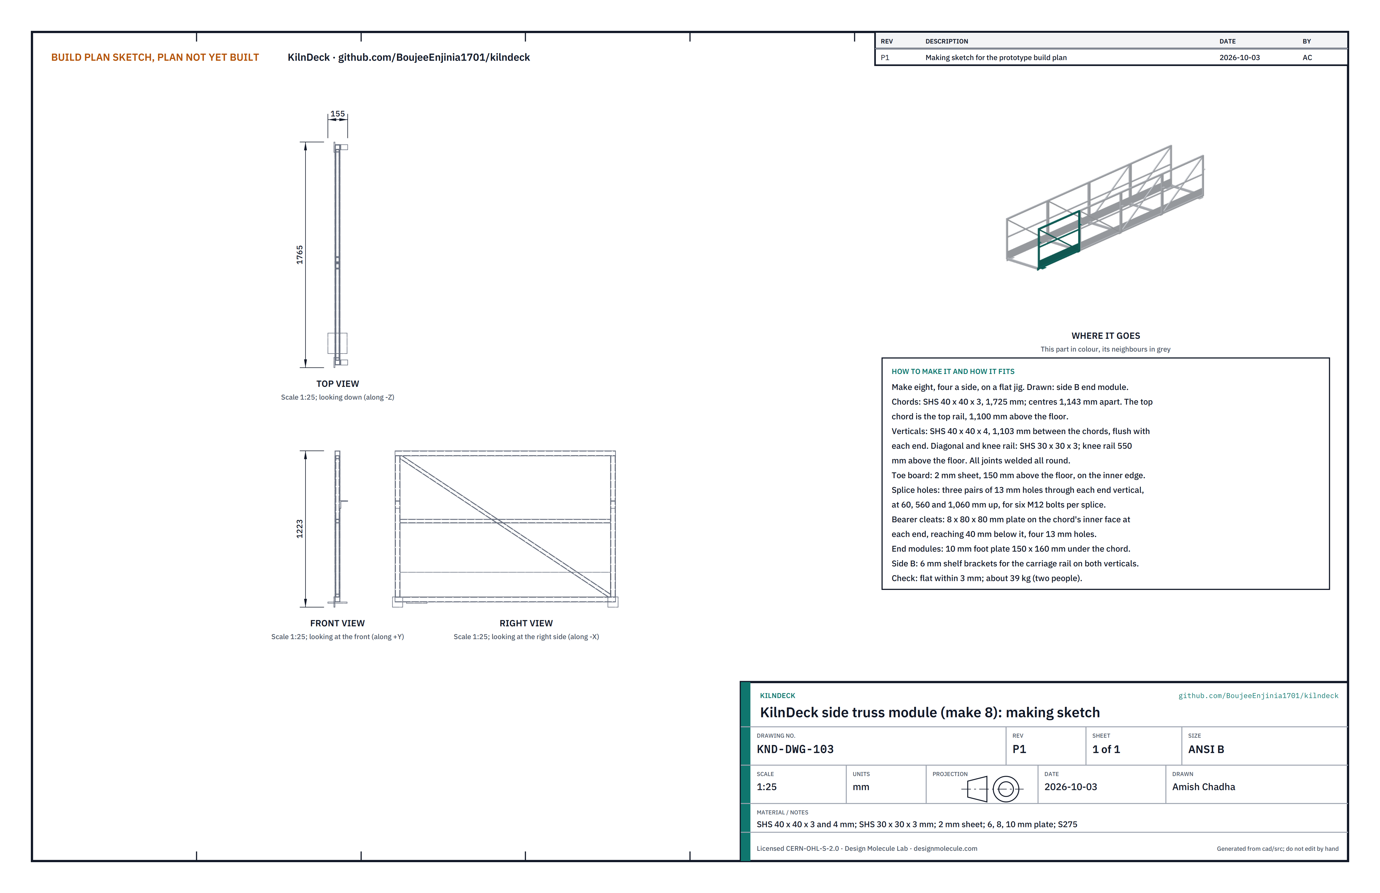
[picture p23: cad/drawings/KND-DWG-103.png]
Figure 6. Making sketch of the side truss module


*Figure 6. Side truss module making sketch (KND-DWG-103).*

**What it is and what it is made from.** Eight welded panels, four per side, that span the trench and are the guardrail. SHS 40 x 40 x 3 for both chords, SHS 40 x 40 x 4 for the end verticals, SHS 30 x 30 x 3 for the diagonal and knee rail, 2 mm sheet for the toe board, 8 mm plate for the bearer cleats, 10 mm plate for the foot plates of the four end modules, 6 mm plate for the carriage rail brackets on the four side B modules.

**How to make it.**

1. Build a flat jig on the workshop floor so every module comes out the same.
2. Cut two chords 1,725 mm long and two end verticals 1,103 mm long. Lay them out as a rectangle with the chords' centre lines 1,143 mm apart and the verticals flush with the chord ends. Weld all round.
3. Fit the knee rail between the verticals with its centre 593 mm above the bottom chord's top face (550 mm above the floor) and one diagonal corner to corner. Make the diagonals of the two middle modules of each side run the other way from the end modules, so they mirror about the middle.
4. Weld a 2 mm toe board along the inner edge of the bottom chord, standing 193 mm above it (150 mm above the floor).
5. Drill three pairs of 13 mm holes through each end vertical, at 60, 560 and 1,060 mm up from the bottom chord, 15 mm each side of its centre, for the splice bolts. Drill the matching modules clamped together.
6. Weld an 8 x 80 x 80 mm cleat to the inner face of the bottom chord at each end, reaching 40 mm below it, with four 13 mm holes.
7. End modules: weld a 10 mm foot plate 150 x 160 mm under the bottom chord over the truck seat, with four 14 mm holes that match the seat.
8. Side B modules: weld a 6 mm shelf bracket to the outer face of each end vertical, its top 750 mm above the floor, for the carriage rail.

**How it fits the parts next to it.** The end modules' foot plates sit on the truck seats (Figure 7). Neighbouring modules bolt face to face through their end verticals with six M12 bolts (Figure 8). The frame bearers bolt to the cleats.

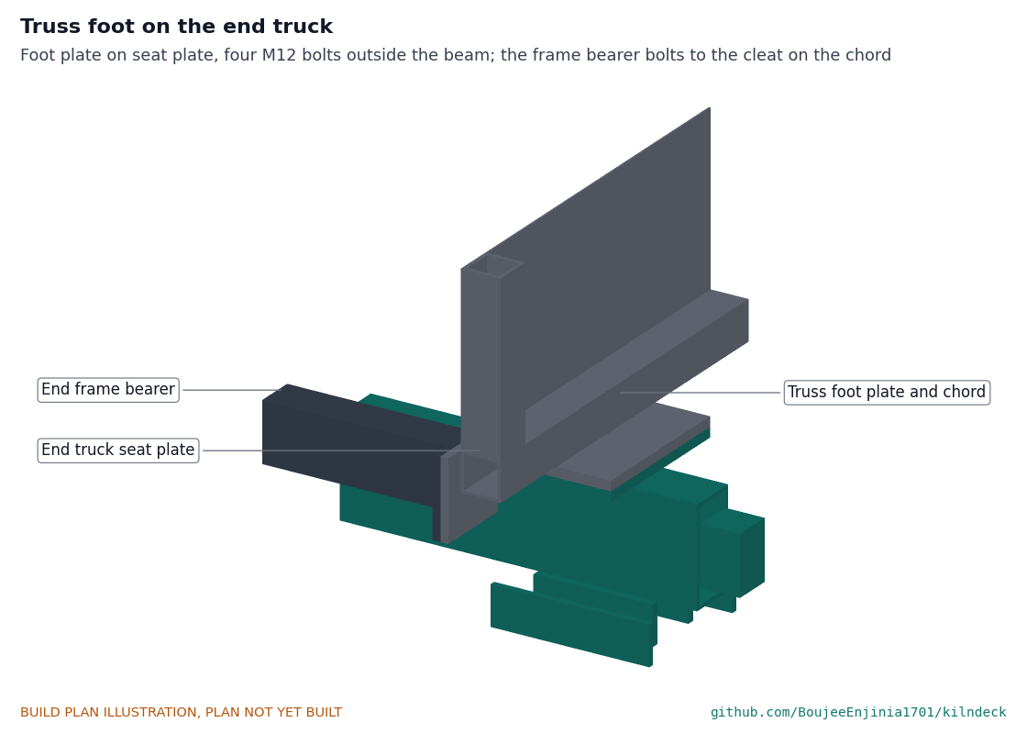
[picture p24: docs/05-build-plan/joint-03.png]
Figure 7. Truss foot on the end truck


*Figure 7. Truss foot plate on the end truck seat.*

**Check before moving on.** Each module is flat within 3 mm and weighs about 39 kg. Two people carry it.

### 3.5 Cross bearers

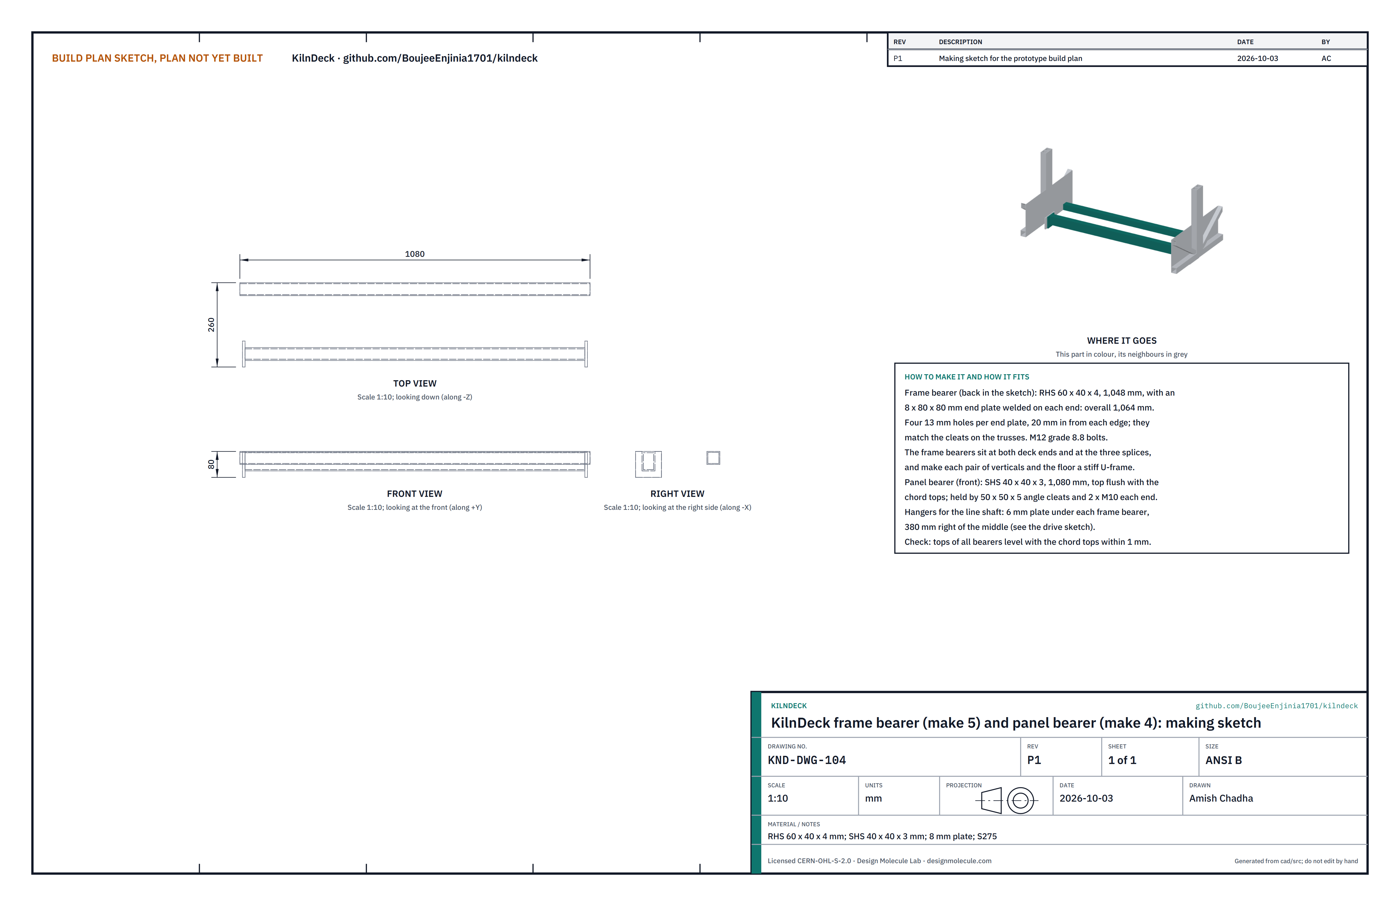
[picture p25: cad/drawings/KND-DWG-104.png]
Figure 8. Making sketch of the bearers


*Figure 8. Frame bearer and panel bearer making sketch (KND-DWG-104).*

**What it is and what it is made from.** Five frame bearers (at the two ends and the three splices) and four panel bearers (in the middle of each module) that carry the floor across the deck. RHS 60 x 40 x 4 and SHS 40 x 40 x 3; 8 mm plate; 6 mm plate for the line shaft hangers.

**How to make it.**

1. Frame bearers: cut five RHS lengths of 1,048 mm, 60 mm side upright. Weld an 8 x 80 x 80 mm end plate on each end (1,064 mm overall) with four 13 mm holes that match the cleats.
2. Under each frame bearer, 380 mm to side B of the middle, weld a 6 mm hanger plate for a pillow block, its bottom 30 mm above the line shaft centre (see section 3.8).
3. Panel bearers: cut four SHS lengths of 1,080 mm with a short angle cleat at each end and two 11 mm holes.

**How it fits the parts next to it.** Each frame bearer's end plates bolt to the cleats of the two trusses with four M12 bolts each end. With the end verticals, this makes a stiff U-frame that keeps the posts upright under a push on the top rail (Figure 9). The tops of all bearers are flush with the tops of the bottom chords.

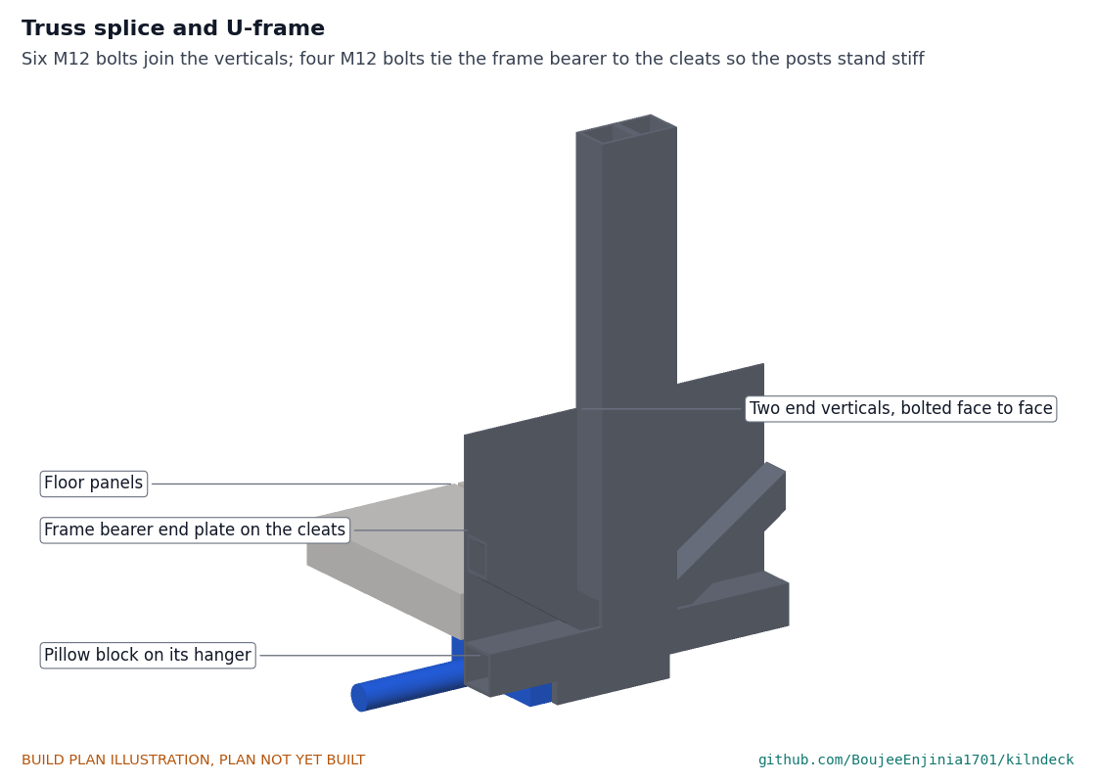
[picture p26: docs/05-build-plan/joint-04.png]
Figure 9. Truss splice and U-frame


*Figure 9. Truss splice, frame bearer and pillow block.*

**Check before moving on.** The bearer tops are level with the chord tops within 1 mm across the deck.

### 3.6 Insulated floor panels

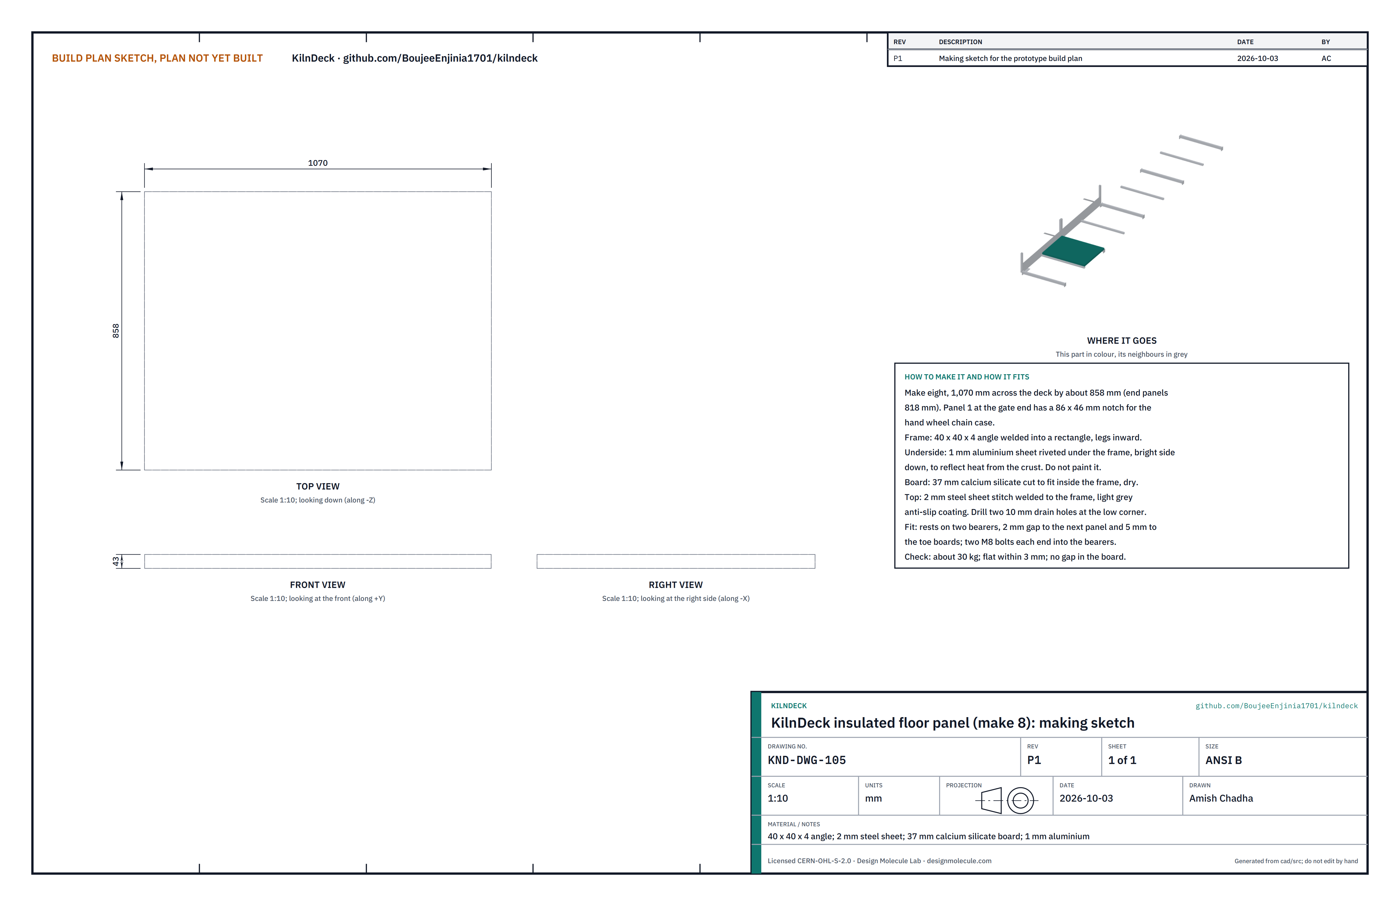
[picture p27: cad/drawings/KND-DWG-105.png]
Figure 10. Making sketch of the floor panel


*Figure 10. Floor panel making sketch (KND-DWG-105).*

**What it is and what it is made from.** Eight panels about 860 x 1,070 mm that the fireman stands on. 40 x 40 x 4 angle; 2 mm steel sheet; 37 mm calcium silicate board; 1 mm aluminium sheet.

**How to make it.**

1. Weld a rectangle of angle, legs inward, 1,070 mm across the deck and the length of its bay (about 858 mm; the two end panels are about 818 mm). Panel 1, at the gate end, has an 86 x 46 mm notch in its side B half for the hand wheel chain case.
2. Rivet the aluminium sheet under the frame, bright side down. Do not paint it: its job is to reflect heat from the crust.
3. Cut the board to fit inside the frame, dry, with no gaps.
4. Stitch weld the 2 mm top sheet to the frame and coat it with light grey anti-slip paint. Drill two 10 mm drain holes at one corner.

**How it fits the parts next to it.** Each panel rests on two bearers with a 4 mm gap to the next panel and 5 mm to the toe boards, and is held by two M8 bolts at each end (Figure 11).

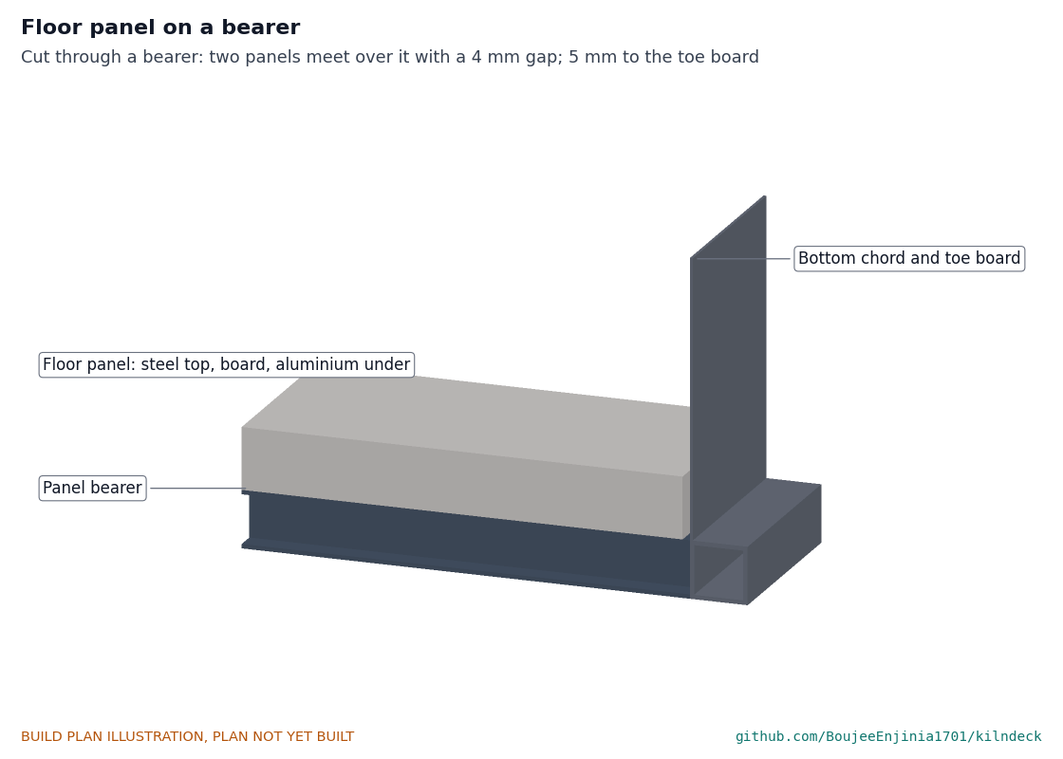
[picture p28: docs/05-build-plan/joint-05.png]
Figure 11. Floor panel on a bearer


*Figure 11. Two floor panels meeting over a bearer, cut through.*

**Check before moving on.** Each panel weighs about 30 kg and is flat within 3 mm.

### 3.7 End rail and gate

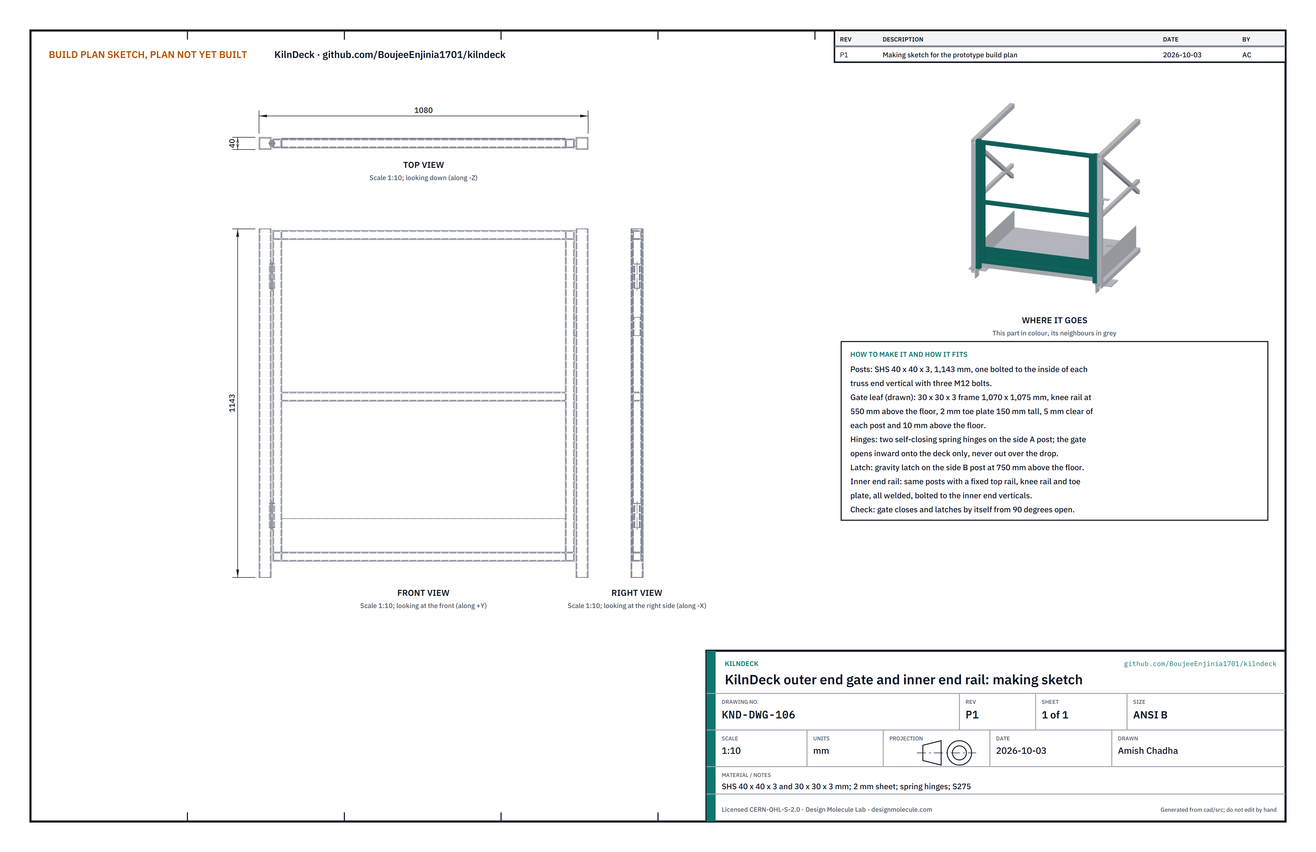
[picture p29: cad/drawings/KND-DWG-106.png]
Figure 12. Making sketch of the end gate


*Figure 12. Outer end gate and inner end rail making sketch (KND-DWG-106).*

**What it is and what it is made from.** The rail that closes the inner end and the gate the fireman uses at the outer end. SHS 40 x 40 x 3 and 30 x 30 x 3; 2 mm sheet; two self-closing spring hinges; a gravity latch.

**How to make it.**

1. Posts: four SHS 40 x 40 x 3 lengths of 1,143 mm, two per end, with three 13 mm holes to bolt them inside the truss end verticals.
2. Inner end rail: a top rail, knee rail at 550 mm above the floor and a 150 mm toe plate between two posts, all welded.
3. Gate leaf: a 30 x 30 x 3 frame 1,070 x 1,075 mm with a knee rail and a 2 mm toe plate, 5 mm clear of each post and 10 mm above the floor.
4. Hang the leaf on two spring hinges on the side A post so it swings inward onto the deck only; a stop on the side B post stops it opening outward. Fit the gravity latch on the side B post about 750 mm above the floor.

**How it fits the parts next to it.** The posts bolt inside the truss end verticals with three M12 bolts each; the bottom of each post stands on the end frame bearer.

**Check before moving on.** Opened to 90 degrees and let go, the gate closes and latches by itself. It cannot be pushed outward.

### 3.8 Travel drive

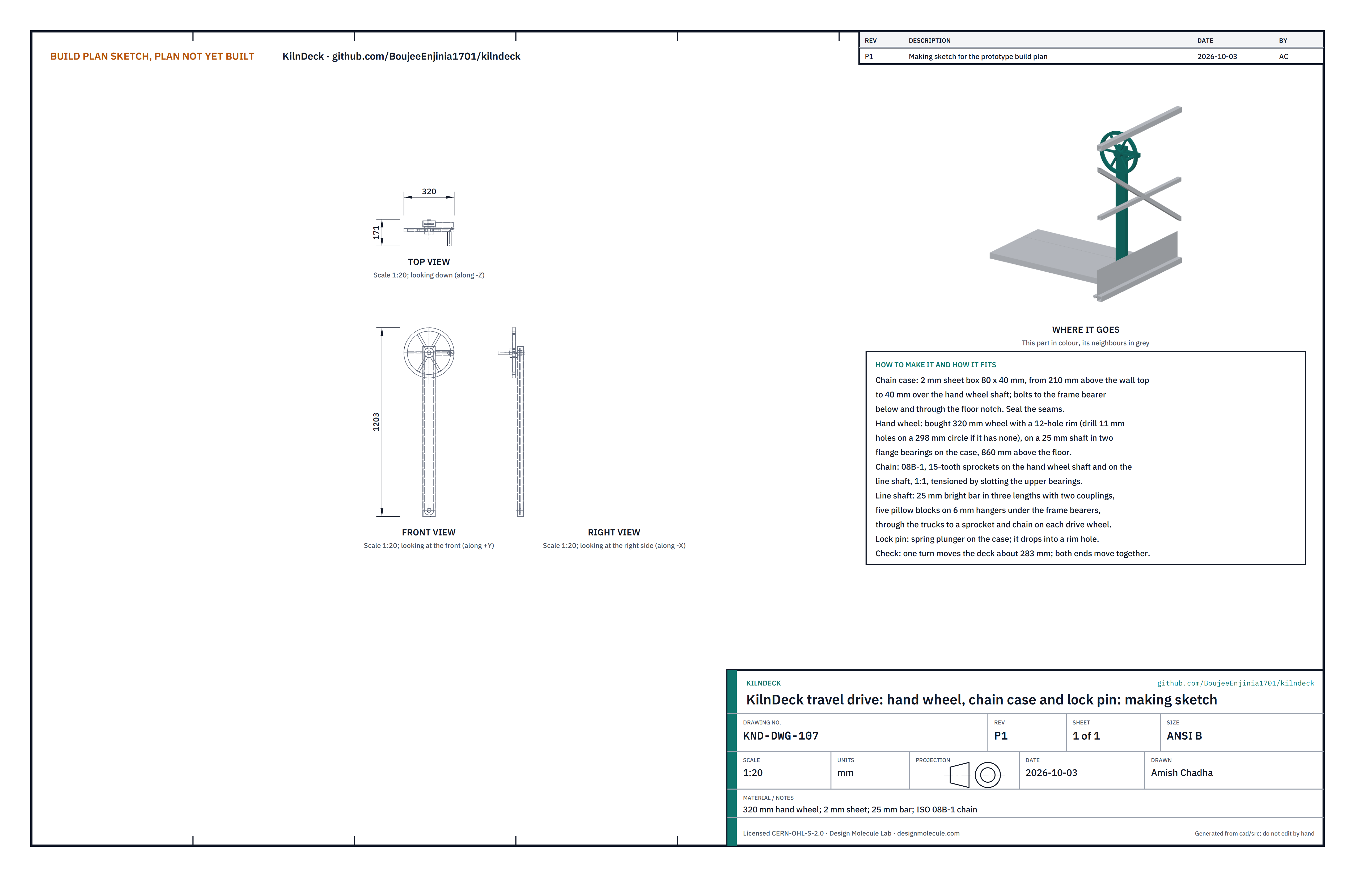
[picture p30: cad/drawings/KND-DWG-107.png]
Figure 13. Making sketch of the hand wheel and chain case


*Figure 13. Hand wheel, chain case and lock pin making sketch (KND-DWG-107).*

**What it is and what it is made from.** The hand wheel that moves the deck, a line shaft under the floor and a chain drive to one wheel at each end. 25 mm bright steel bar in three lengths; two rigid couplings; five UCP205 pillow blocks; three ISO 08B-1 chains and six 15-tooth sprockets; a 320 mm hand wheel; 2 mm sheet for the chain case and guards; a spring lock plunger.

**How to make it.**

1. Line shaft: cut three lengths of 25 mm bar that together run 6,760 mm, from 30 mm outside one truck to 30 mm outside the other. Cut keyways for the end sprockets and the hand wheel chain sprocket.
2. Chain case: a sealed 2 mm sheet box 80 x 40 mm in plan, from 210 mm above the wall top to 40 mm above the hand wheel shaft, with two flange bearings for a short 25 mm hand wheel shaft 860 mm above the floor.
3. Hand wheel: if its rim has no holes, drill twelve 11 mm holes on a 298 mm circle. Fit the spring plunger on the case so its pin drops into a rim hole.
4. End guards: a 2 mm sheet cover for each end chain drive, bolted to the outside of the truck.

**How it fits the parts next to it.** The line shaft runs under the floor on pillow blocks bolted to the hangers under the frame bearers, through the 32 mm holes in both trucks, to a sprocket at each end; a short chain drives the sprocket on the side B wheel axle (Figure 14). The chain case stands on the end frame bearer, passes up through the notch in floor panel 1 and carries the hand wheel on side B, about 0.7 m in from the gate (Figure 15).

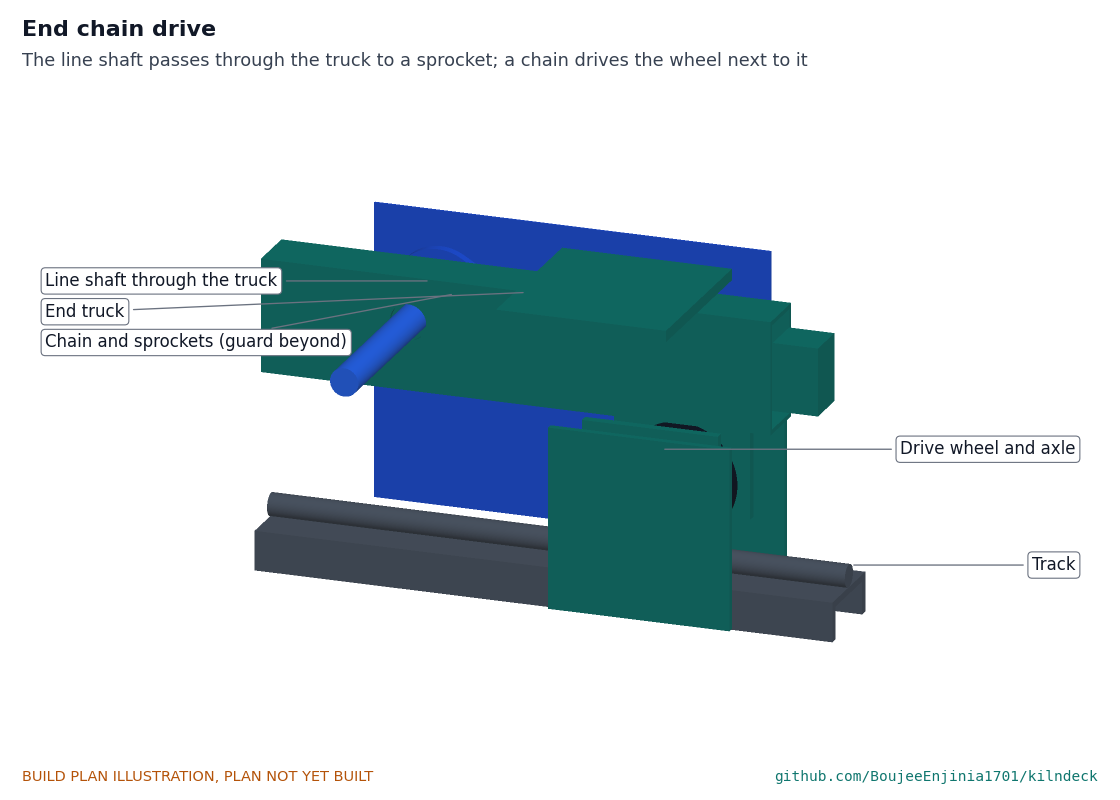
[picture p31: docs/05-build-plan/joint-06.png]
Figure 14. End chain drive


*Figure 14. End chain drive at the inner truck.*

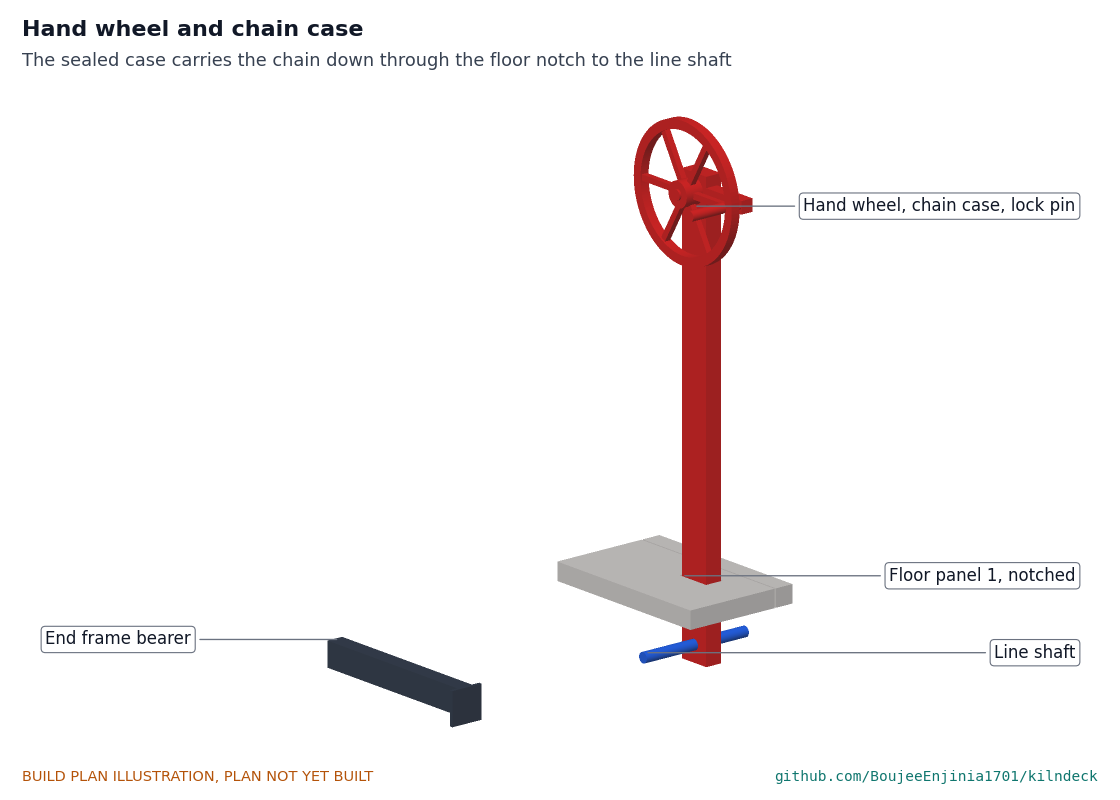
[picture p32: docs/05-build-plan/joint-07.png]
Figure 15. Hand wheel and chain case


*Figure 15. Hand wheel, sealed chain case and lock pin.*

**Check before moving on.** With the deck on its wheels, one turn of the hand wheel moves both ends about 283 mm, together. With the pin in, the deck cannot be pushed.

### 3.9 Carriage rail

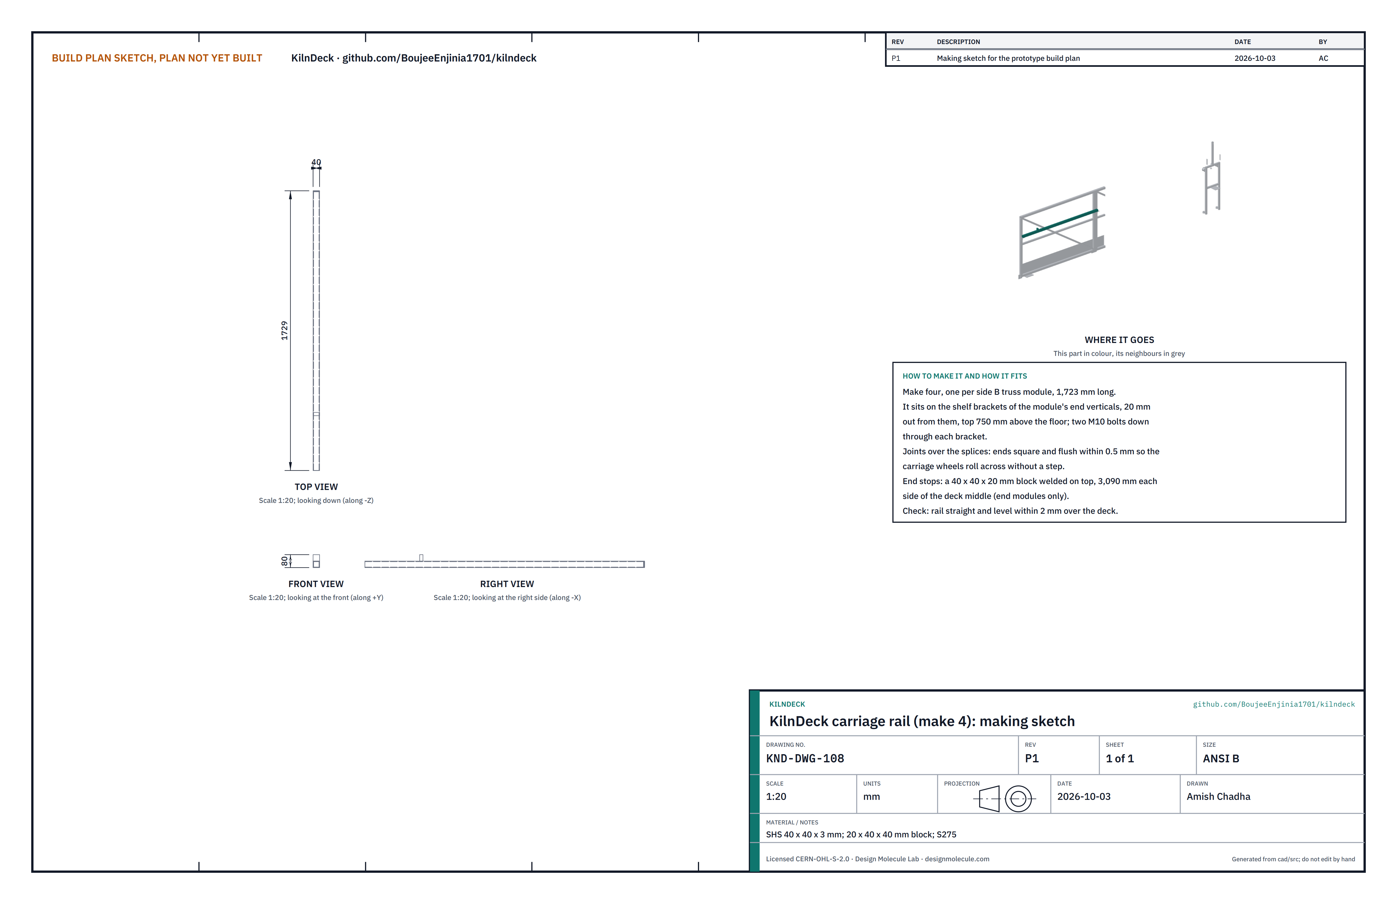
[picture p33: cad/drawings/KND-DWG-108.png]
Figure 16. Making sketch of the carriage rail


*Figure 16. Carriage rail making sketch (KND-DWG-108).*

**What it is and what it is made from.** Four lengths of SHS 40 x 40 x 3, 1,723 mm each, that the hopper carriage runs on along the outside of truss B, with two small end stops.

**How to make it.** Cut four lengths with square ends. Drill two 11 mm holes at each end to match the shelf brackets. On the two end lengths, weld a 40 x 40 x 20 mm stop block on top, 3,090 mm each side of the deck middle.

**How it fits the parts next to it.** The rail sits on the shelf brackets of the truss B end verticals, 20 mm out from them, top 750 mm above the floor, held by two M10 bolts at each bracket. Ends meet flush over the splices.

**Check before moving on.** The rail is straight and level within 2 mm along the deck, with no step at the joints.

### 3.10 Hopper carriage frame

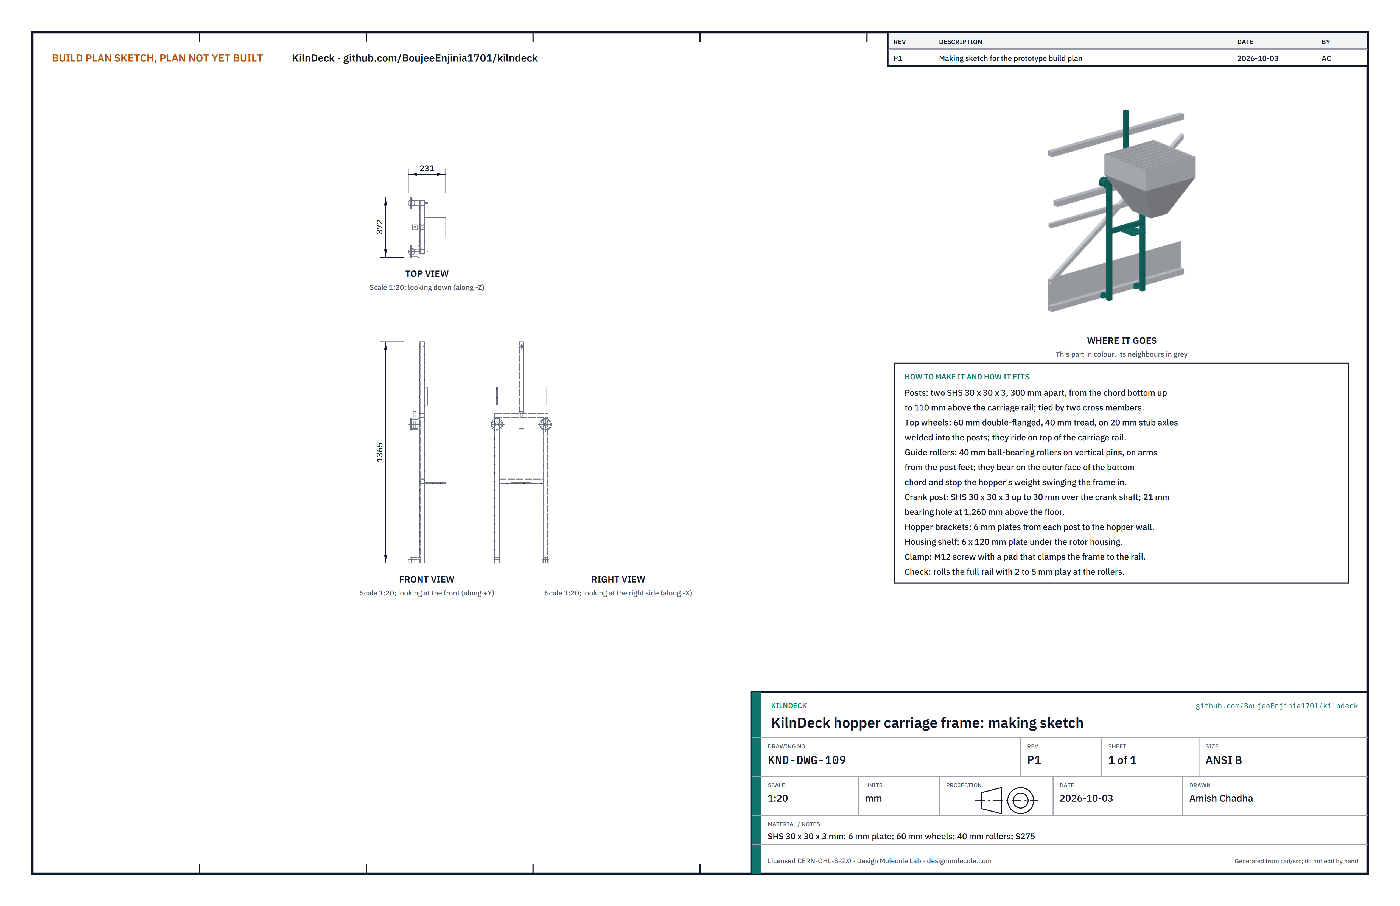
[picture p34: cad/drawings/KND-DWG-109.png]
Figure 17. Making sketch of the hopper carriage frame


*Figure 17. Hopper carriage frame making sketch (KND-DWG-109).*

**What it is and what it is made from.** The frame that carries the hopper along the deck. SHS 30 x 30 x 3; 6 mm plate; two 60 mm double-flanged wheels; two 40 mm ball-bearing rollers; an M12 clamp screw.

**How to make it.**

1. Two posts 300 mm apart, from the level of the bottom chord up to about 110 mm above the carriage rail, joined by cross members at the top and at the rotor housing.
2. Weld a 20 mm stub axle into each post near the top for a wheel that rides on top of the rail.
3. At the foot of each post weld an arm that carries a 40 mm roller on a vertical pin, bearing on the outer face of the bottom chord.
4. Weld a crank post on the top cross member with a 21 mm bearing hole 1,260 mm above the floor.
5. Weld two 6 mm hopper brackets and a 6 x 120 mm shelf for the rotor housing.
6. Fit the M12 clamp screw with a pad that presses on the rail.

**How it fits the parts next to it.** The wheels sit on the rail; the hopper's weight, hanging outside, presses the rollers against the bottom chord (Figure 18).

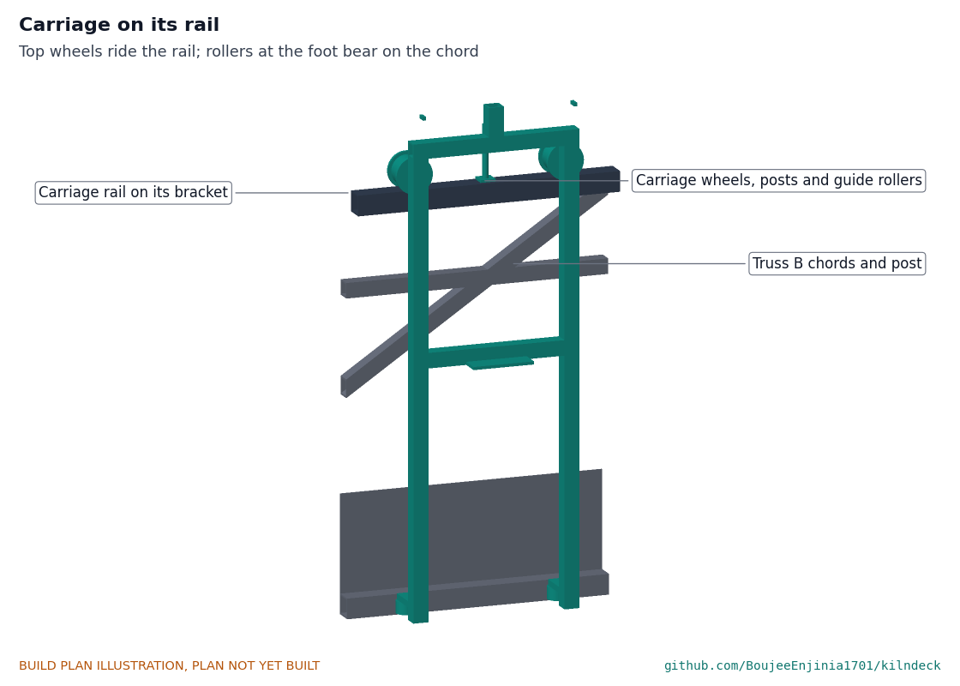
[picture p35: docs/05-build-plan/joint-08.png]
Figure 18. Carriage on its rail


*Figure 18. Carriage wheels on the rail and guide rollers on the bottom chord.*

**Check before moving on.** The frame rolls the full length of a test rail with 2 to 5 mm of play at the rollers.

### 3.11 Fuel hopper

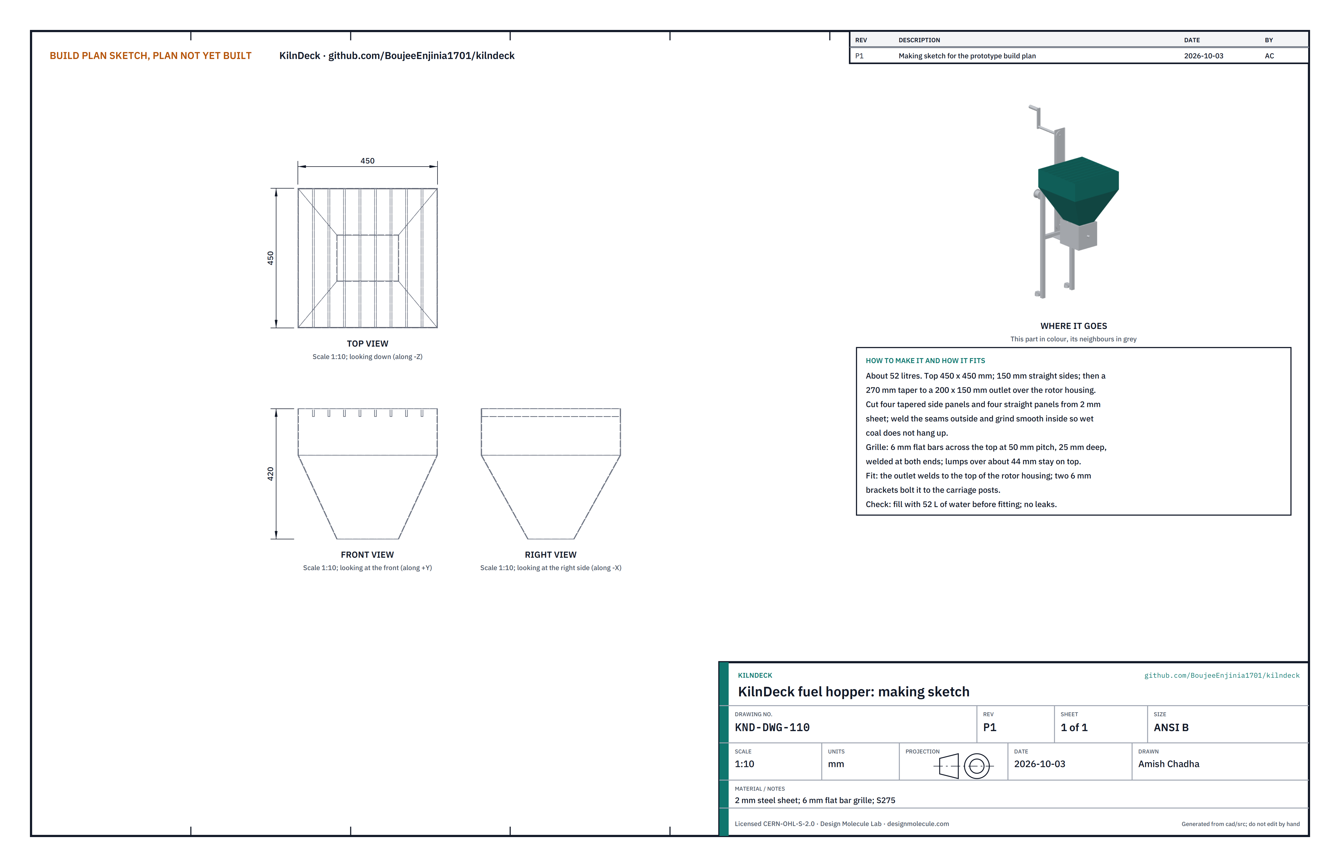
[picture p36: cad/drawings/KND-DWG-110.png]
Figure 19. Making sketch of the fuel hopper


*Figure 19. Fuel hopper making sketch (KND-DWG-110).*

**What it is and what it is made from.** A hopper of about 52 litres. 2 mm steel sheet; 6 mm flat bar for the grille.

**How to make it.** Cut four straight panels (450 x 150 mm) and four tapered panels that run from a 450 x 450 mm top to a 200 x 150 mm outlet over 270 mm. Weld the seams outside and grind them smooth inside so wet coal does not hang up. Weld 6 mm bars across the top at 50 mm pitch, 25 mm deep.

**How it fits the parts next to it.** The outlet welds to the top of the rotor housing; two brackets bolt the hopper to the carriage posts.

**Check before moving on.** Filled with water before fitting, it does not leak.

### 3.12 Metering rotor, housing and crank

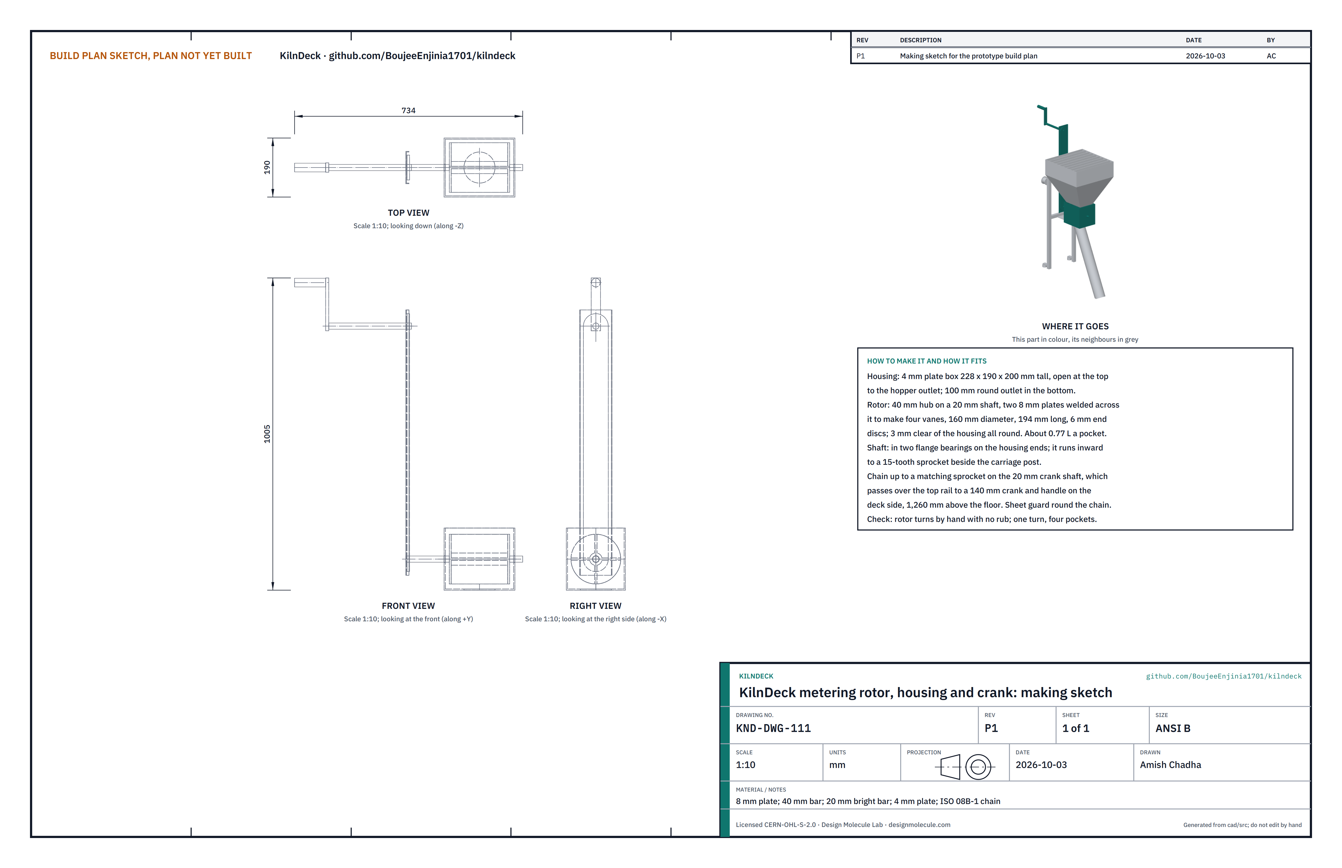
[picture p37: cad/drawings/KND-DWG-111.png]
Figure 20. Making sketch of the metering rotor


*Figure 20. Metering rotor, housing and crank making sketch (KND-DWG-111).*

**What it is and what it is made from.** The part that measures fuel into the spout. 4 mm plate for the housing; 40 mm bar for the hub; 8 mm plate for the vanes; 20 mm bright bar for the shafts; two flange bearings; an ISO 08B-1 chain and two sprockets; 2 mm sheet guard; a crank and handle.

**How to make it.**

1. Housing: a 4 mm plate box 228 x 190 mm, 200 mm tall, open at the top and with a 100 mm round outlet in the bottom with a lip for the spout collar.
2. Rotor: weld two 8 mm plates across a 40 mm hub on a 20 mm shaft to make four vanes 160 mm across and 194 mm long, with 6 mm discs on the ends, 3 mm clear of the housing all round.
3. Mount the shaft in flange bearings on the housing ends, running inward to a sprocket beside the carriage post.
4. Crank shaft: 20 mm bar through the crank post, from a sprocket above the rotor sprocket inward over the top rail to a 140 mm crank arm and handle on the deck side.
5. Chain between the two sprockets inside a 2 mm sheet guard.

**How it fits the parts next to it.** The housing sits on its shelf under the hopper outlet; the spout collar hangs on its outlet lip (Figure 21).

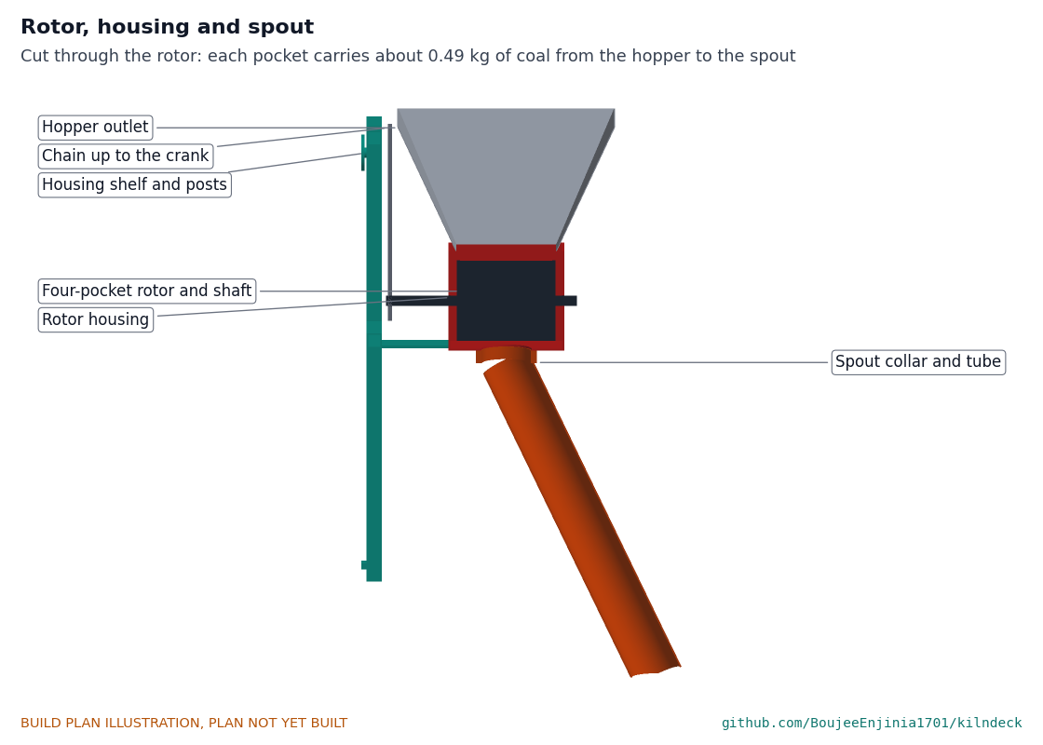
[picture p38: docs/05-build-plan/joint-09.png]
Figure 21. Rotor, housing and spout


*Figure 21. Rotor in its housing, cut through, with the spout collar below.*

**Check before moving on.** The rotor turns by hand with no rub; a full turn moves four pockets past the outlet.

### 3.13 Swing spout

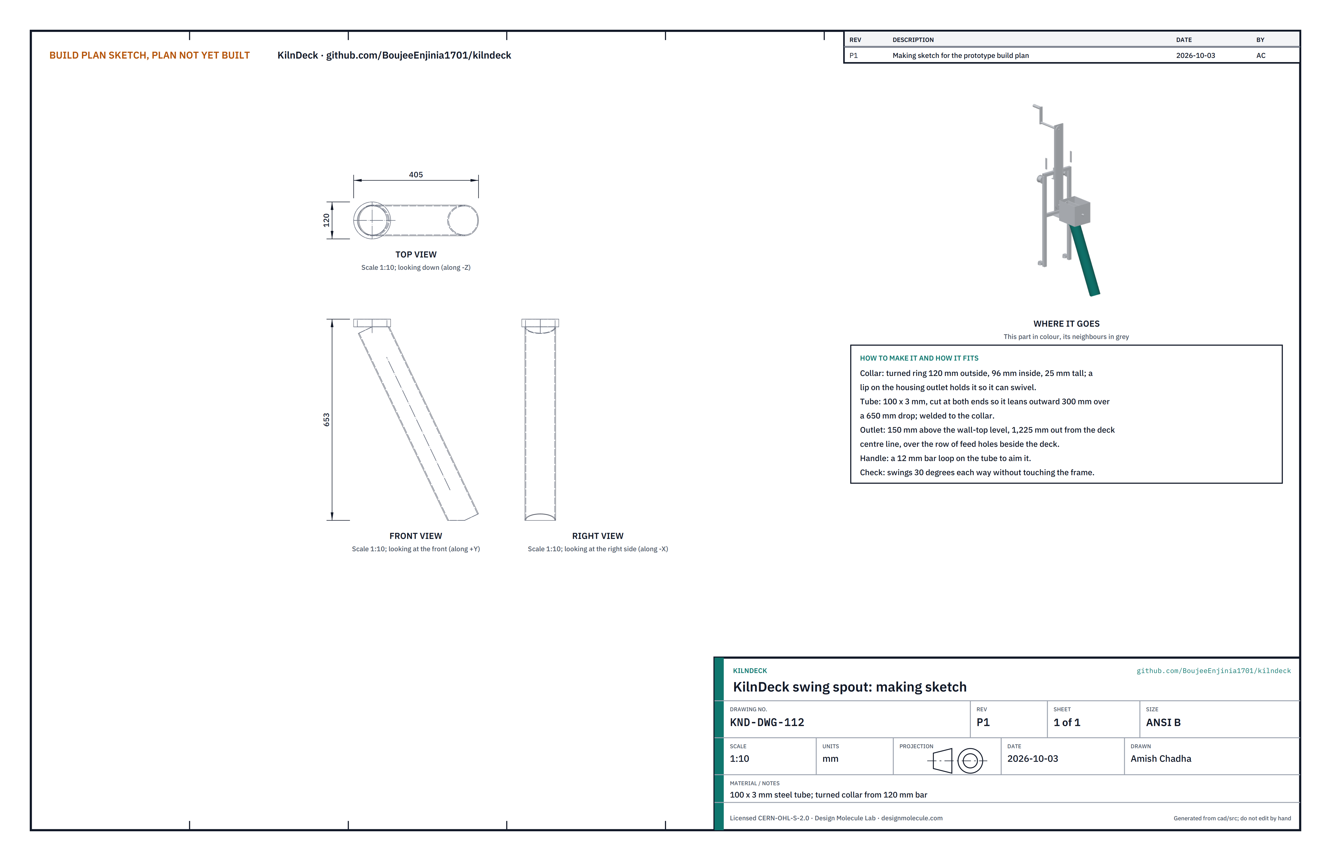
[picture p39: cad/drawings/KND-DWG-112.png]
Figure 22. Making sketch of the swing spout


*Figure 22. Swing spout making sketch (KND-DWG-112).*

**What it is and what it is made from.** The tube that carries fuel from the rotor into the feed hole. 100 x 3 mm steel tube; a collar turned from 120 mm bar.

**How to make it.** Turn a collar 120 mm outside, 96 mm inside, 25 mm tall, that hooks over the lip on the housing outlet and turns on it. Cut the tube so it leans outward 300 mm over a drop of about 650 mm, and weld it to the collar. Weld a 12 mm bar loop on the tube as a handle.

**How it fits the parts next to it.** The outlet ends 150 mm above wall-top level and 1,225 mm out from the deck centre line, over the row of feed holes beside the deck.

**Check before moving on.** It swings 30 degrees each way without touching the frame.

### 3.14 Grip sleeves (bought)

Buy 11 m of silicone rubber sleeve for a 40 mm square rail, rated to 200 °C. Cut it into lengths that fit between the posts on both top rails, leaving 120 mm clear at each post where the diagonals meet the rail.

## 4. Putting it together

Assemble on the kiln over the cold zone (no fire beneath), on a straight side. Two people lift each piece. Keep the deck on trestles until the floor is on.

### Step 1: levelling pads

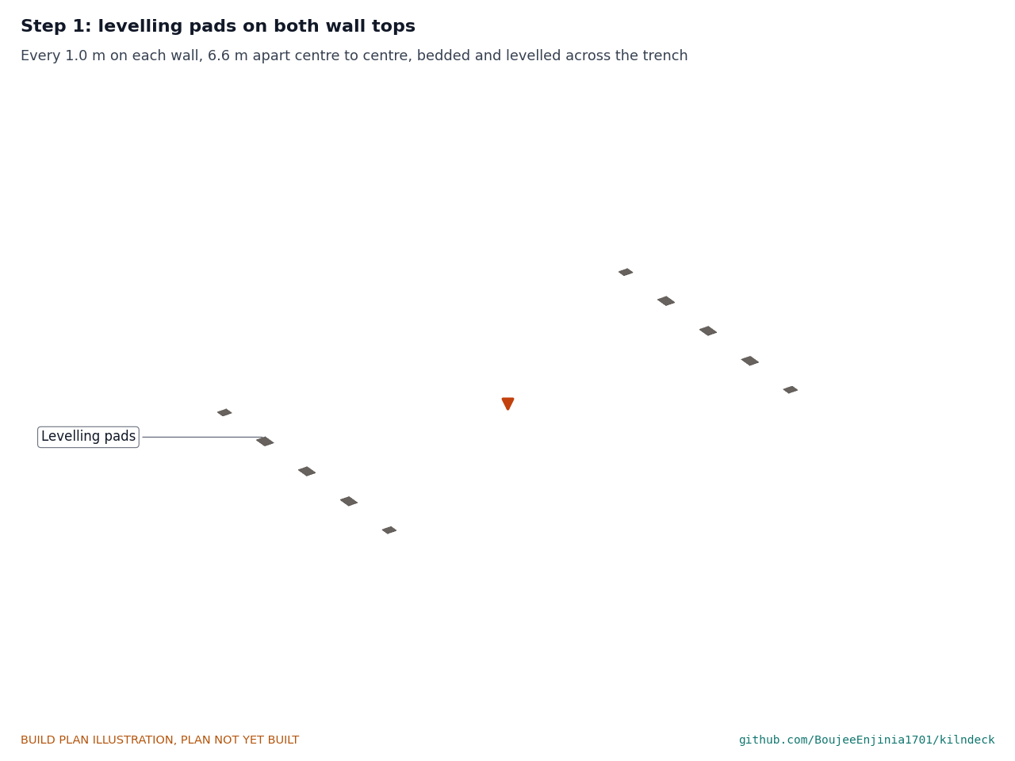
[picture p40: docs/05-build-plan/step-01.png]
Figure 23. Step 1


*Figure 23. Step 1: levelling pads on both wall tops.*

Set out two lines 6,600 mm apart, one on each wall top. Bed a pad every 1,000 mm on a thin lime-sand mortar and level all pads across the trench within 5 mm, using shims. **Hold point:** the wall-top survey must be complete and the walls judged sound before any pad is laid.

### Step 2: track modules

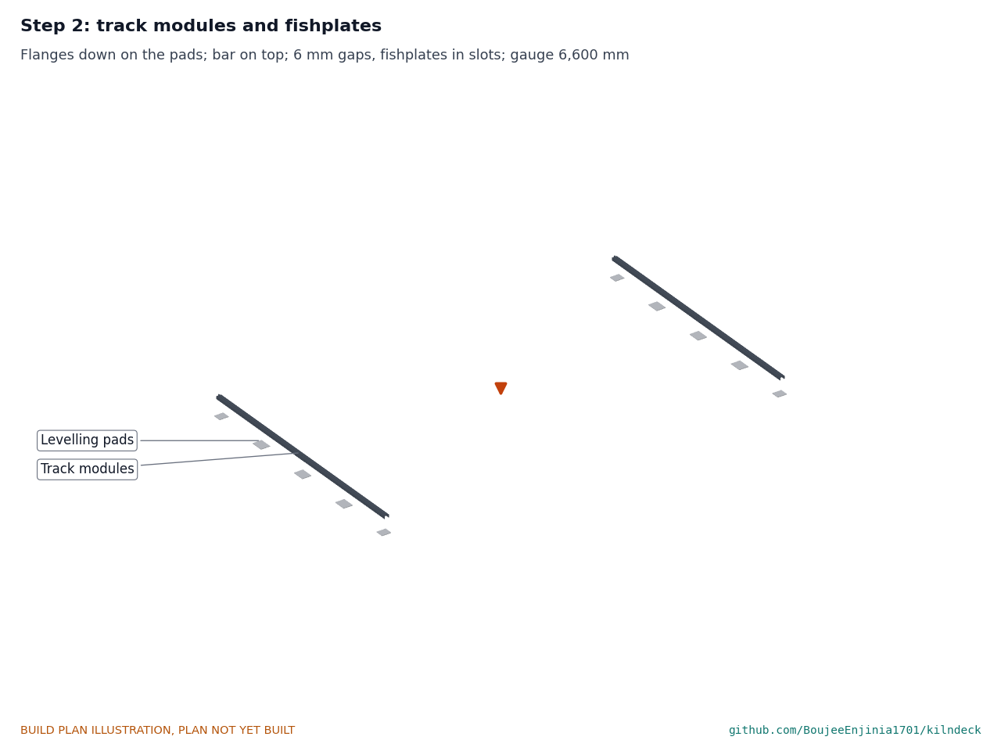
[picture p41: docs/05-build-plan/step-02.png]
Figure 24. Step 2


*Figure 24. Step 2: track modules and fishplates.*

Lay the modules flanges down on the pads with 6 mm gaps; bolt the fishplates finger tight plus a quarter turn so the joints can slide. Check the gauge, 6,600 mm between the bar centres, every 1,000 mm, within 5 mm.

### Step 3: end stops

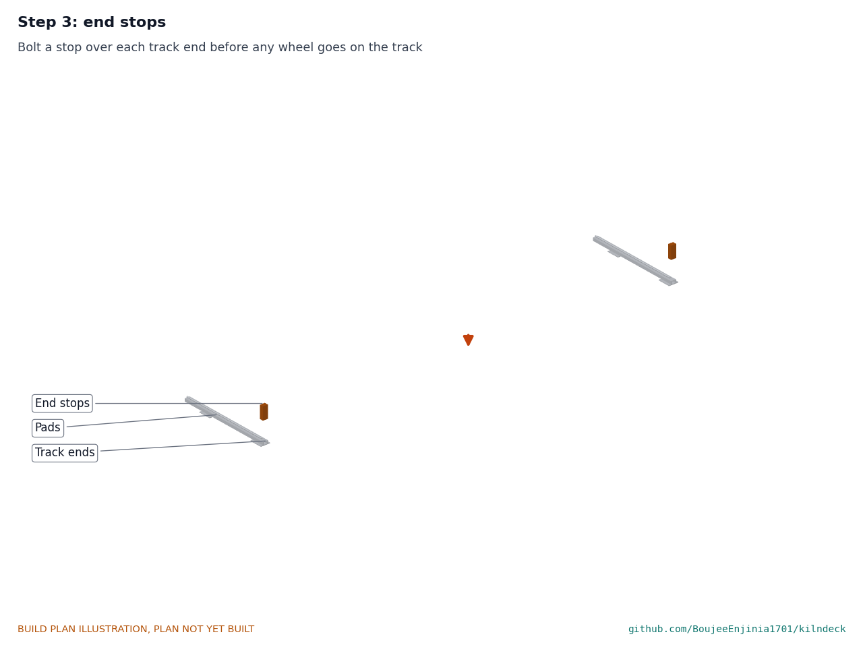
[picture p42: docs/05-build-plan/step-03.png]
Figure 25. Step 3


*Figure 25. Step 3: end stops at the track ends.*

Bolt a stop over each of the four track ends before any wheel goes on the track.

### Step 4: end trucks onto the tracks

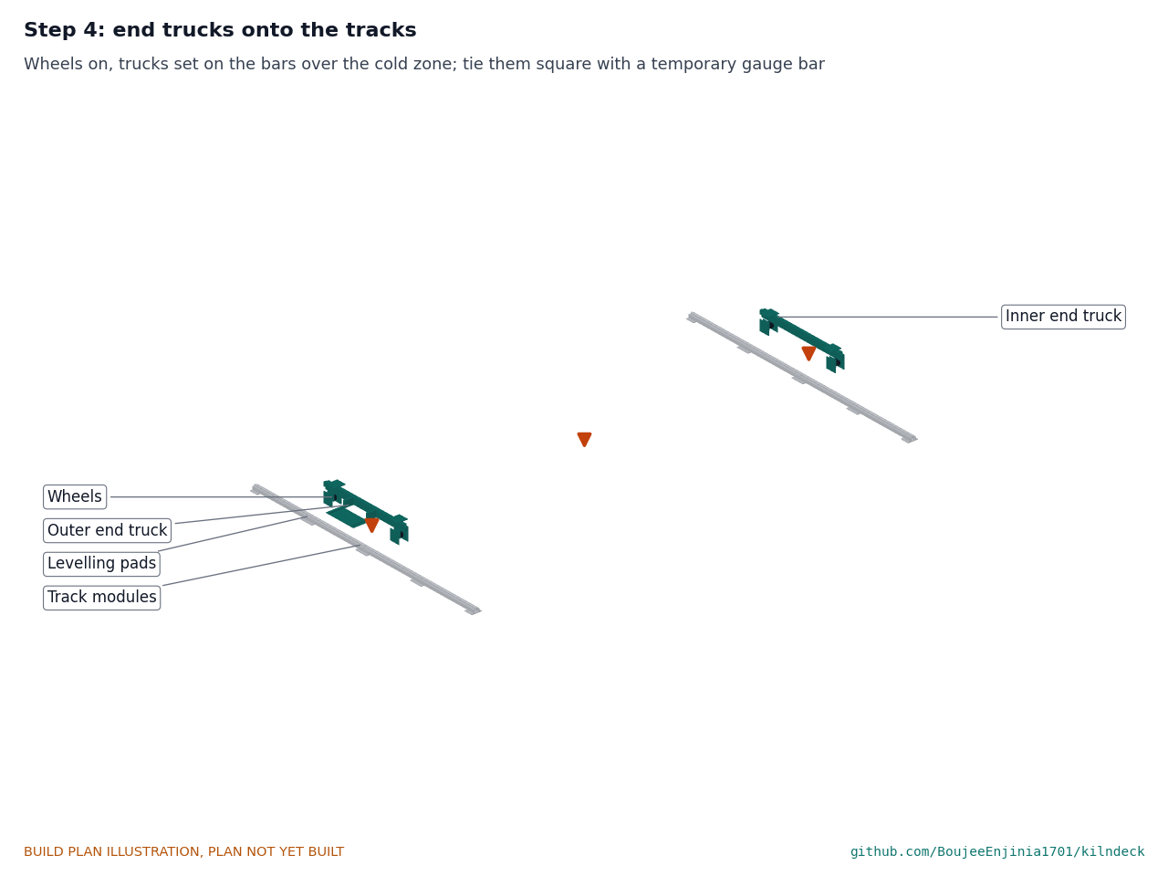
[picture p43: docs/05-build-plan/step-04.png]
Figure 26. Step 4


*Figure 26. Step 4: end trucks with their wheels onto the tracks.*

Fit the wheels in the forks (wide-groove wheels on the inner truck). Set both trucks on the bars and tie them square with a temporary gauge bar between their side A ends.

### Step 5: side truss A

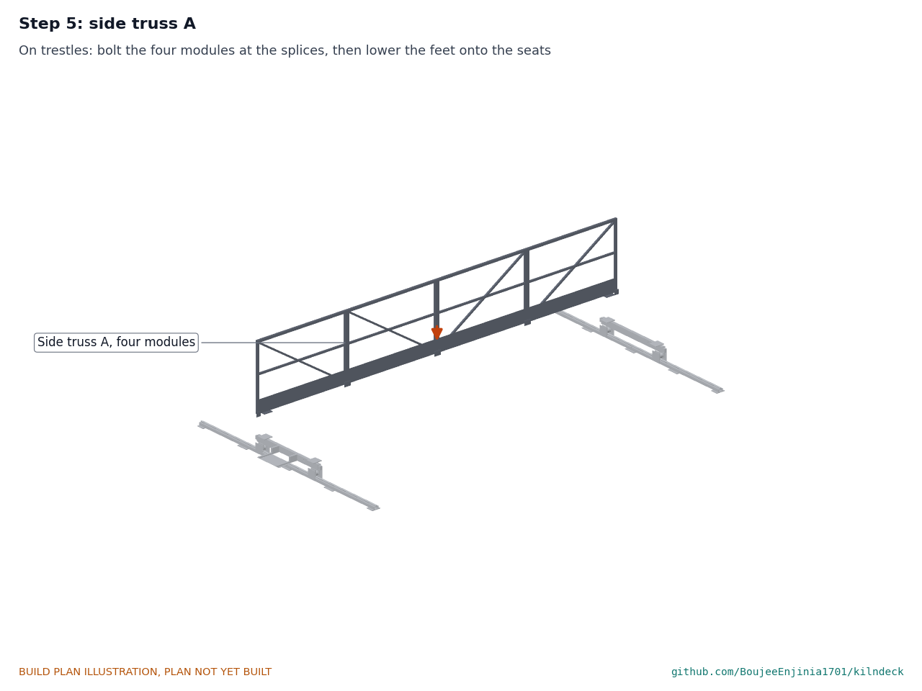
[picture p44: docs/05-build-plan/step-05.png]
Figure 27. Step 5


*Figure 27. Step 5: side truss A on its trucks.*

Set trestles across the cold zone at the height of the truck seats. Lay the four side A modules on them, bolt the splices with six M12 bolts each, then lower the foot plates onto the seats and bolt them with four M12 bolts each.

### Step 6: side truss B

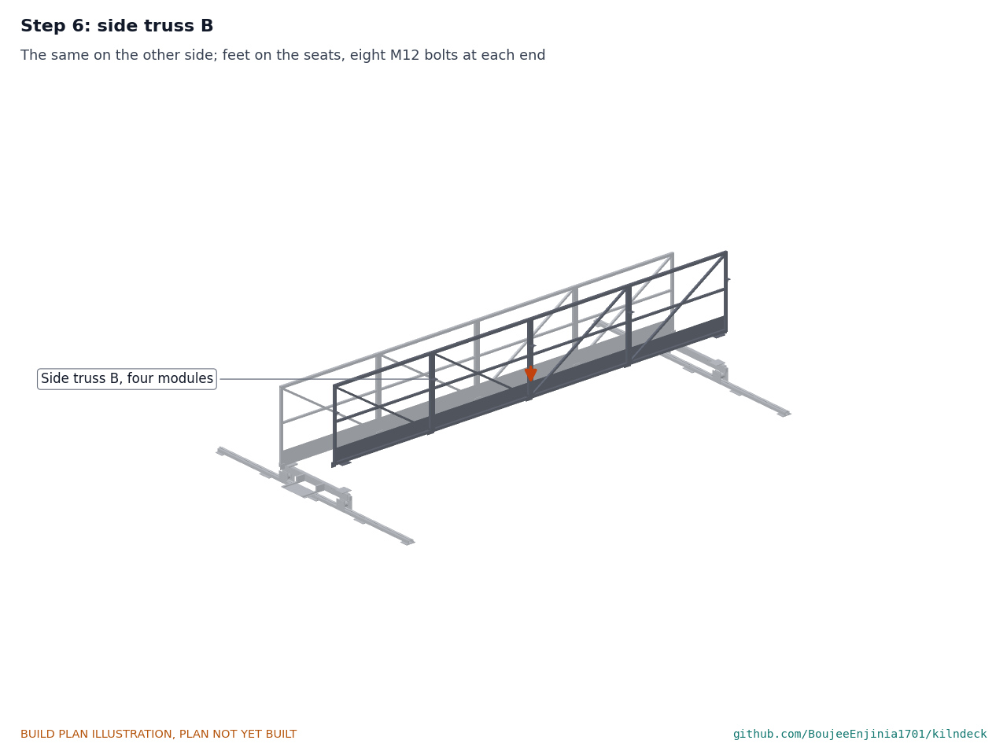
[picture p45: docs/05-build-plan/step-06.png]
Figure 28. Step 6


*Figure 28. Step 6: side truss B on its trucks.*

The same on side B. Remove the gauge bar.

### Step 7: cross bearers

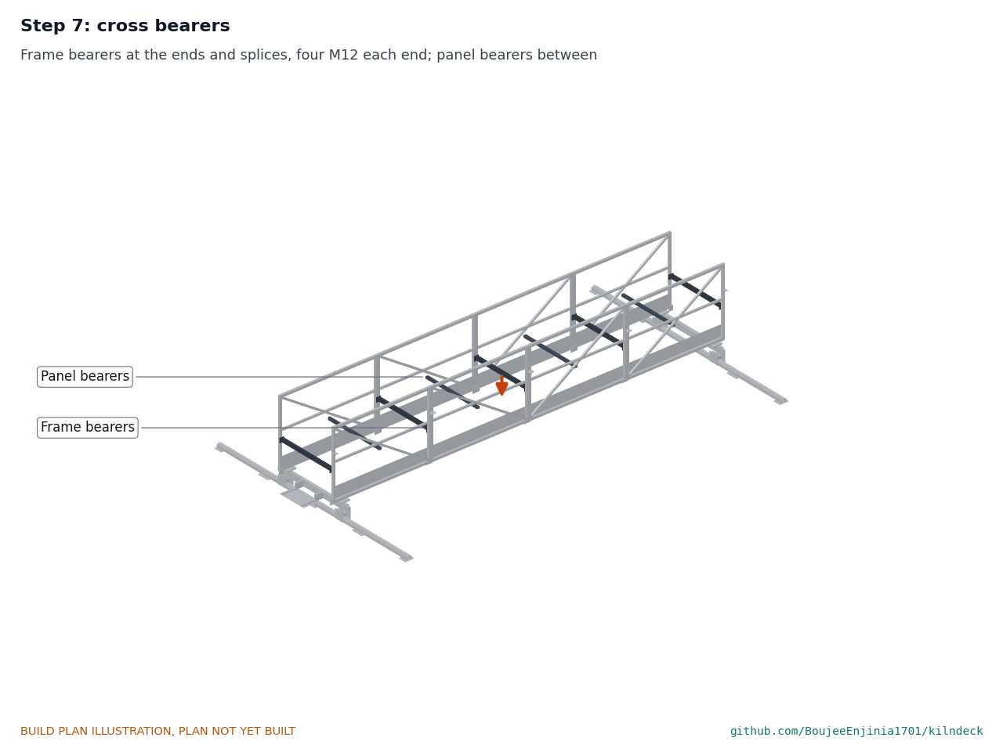
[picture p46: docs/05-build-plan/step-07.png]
Figure 29. Step 7


*Figure 29. Step 7: frame bearers and panel bearers.*

Bolt the five frame bearers to the cleats with four M12 bolts at each end, then the four panel bearers with two M10 bolts each end. Tighten the frame bearers fully; they make the posts stiff.

### Step 8: floor panels

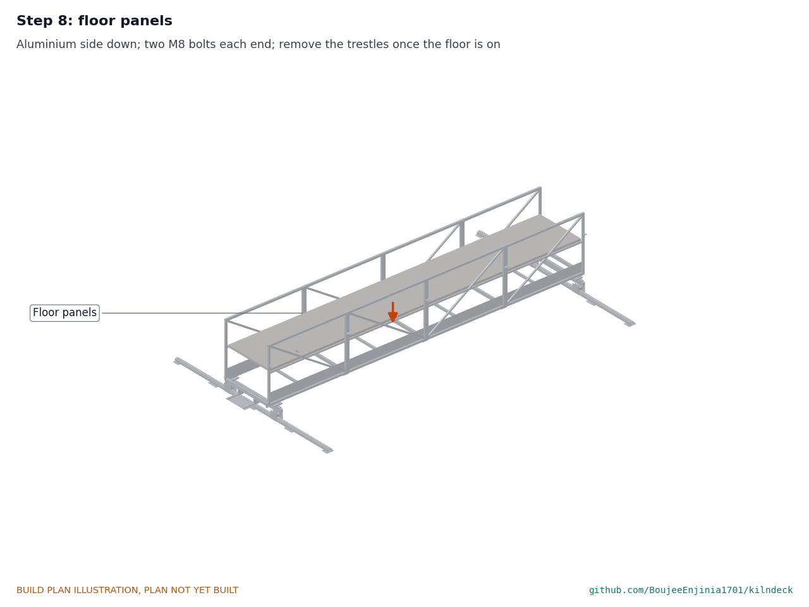
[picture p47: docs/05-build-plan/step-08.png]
Figure 30. Step 8


*Figure 30. Step 8: floor panels.*

Lay the eight panels aluminium side down, panel 1 (notched) at the gate end on side B; bolt each end with two M8 bolts. Remove the trestles.

### Step 9: end rail, gate and grips

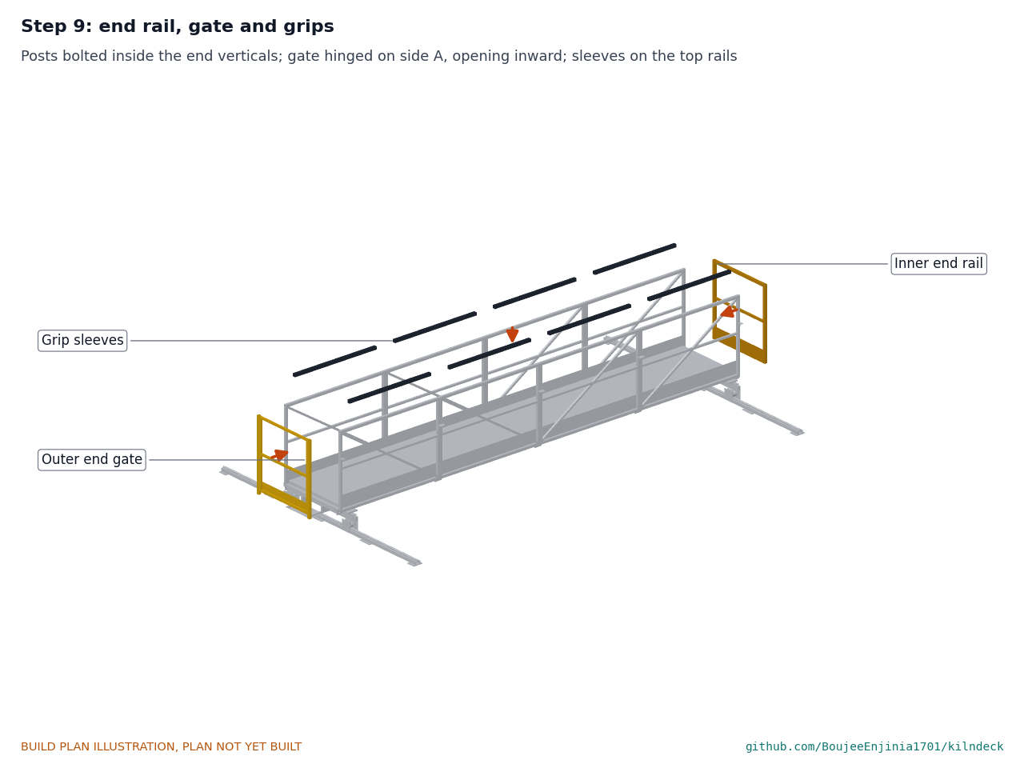
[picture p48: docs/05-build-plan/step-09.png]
Figure 31. Step 9


*Figure 31. Step 9: inner end rail, outer gate and grip sleeves.*

Bolt the inner end rail and the gate posts inside the end verticals. Hang the gate on side A so it opens inward. Fit the grip sleeves on both top rails.

### Step 10: line shaft

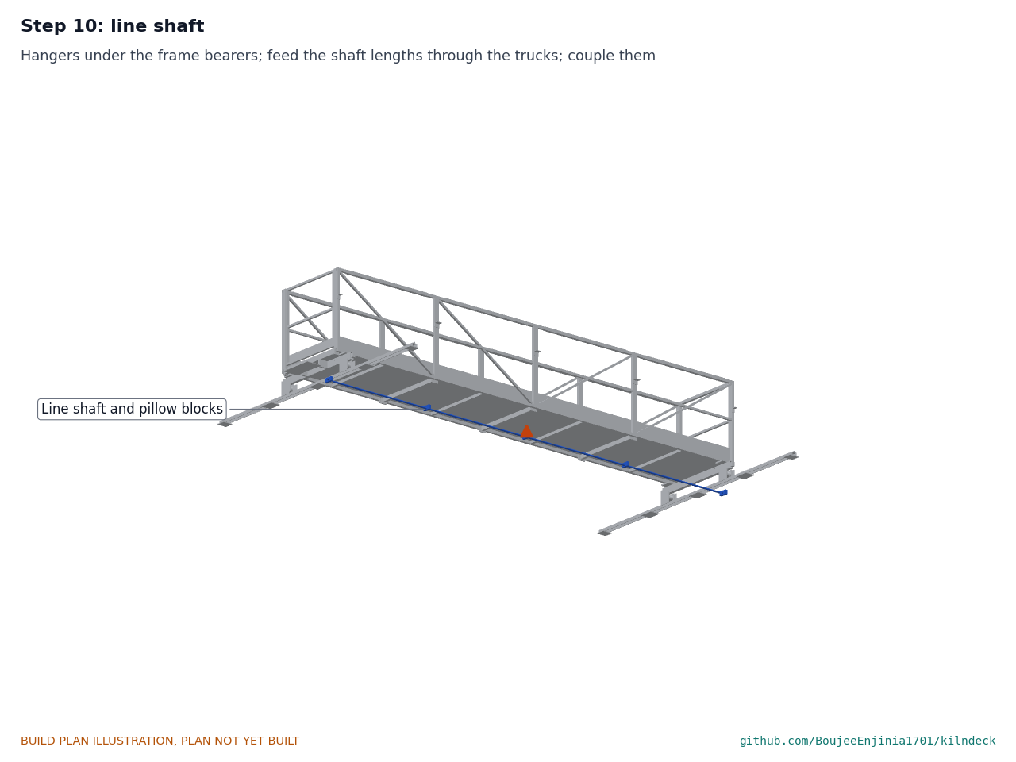
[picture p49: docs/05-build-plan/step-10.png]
Figure 32. Step 10


*Figure 32. Step 10: line shaft and pillow blocks, seen from below.*

Bolt the pillow blocks to the hangers. Feed the shaft lengths through the trucks and blocks and join them with the couplings; lock the block collars.

### Step 11: end chain drives

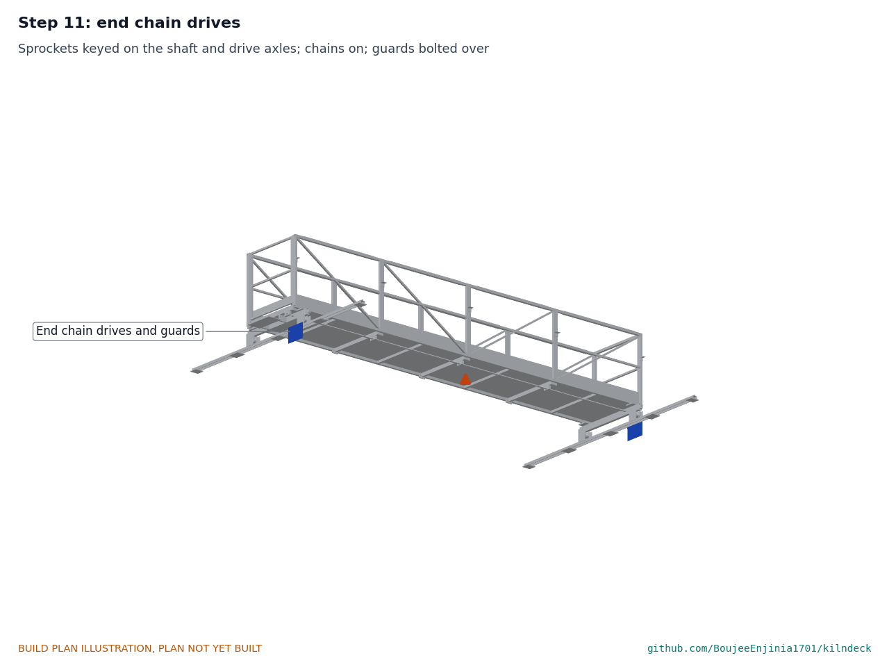
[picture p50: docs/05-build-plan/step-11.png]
Figure 33. Step 11


*Figure 33. Step 11: end chain drives and guards, seen from below.*

Key a sprocket on each end of the line shaft and on each side B wheel axle; fit the chains with about 5 mm of slack; bolt the guards over them.

### Step 12: hand wheel

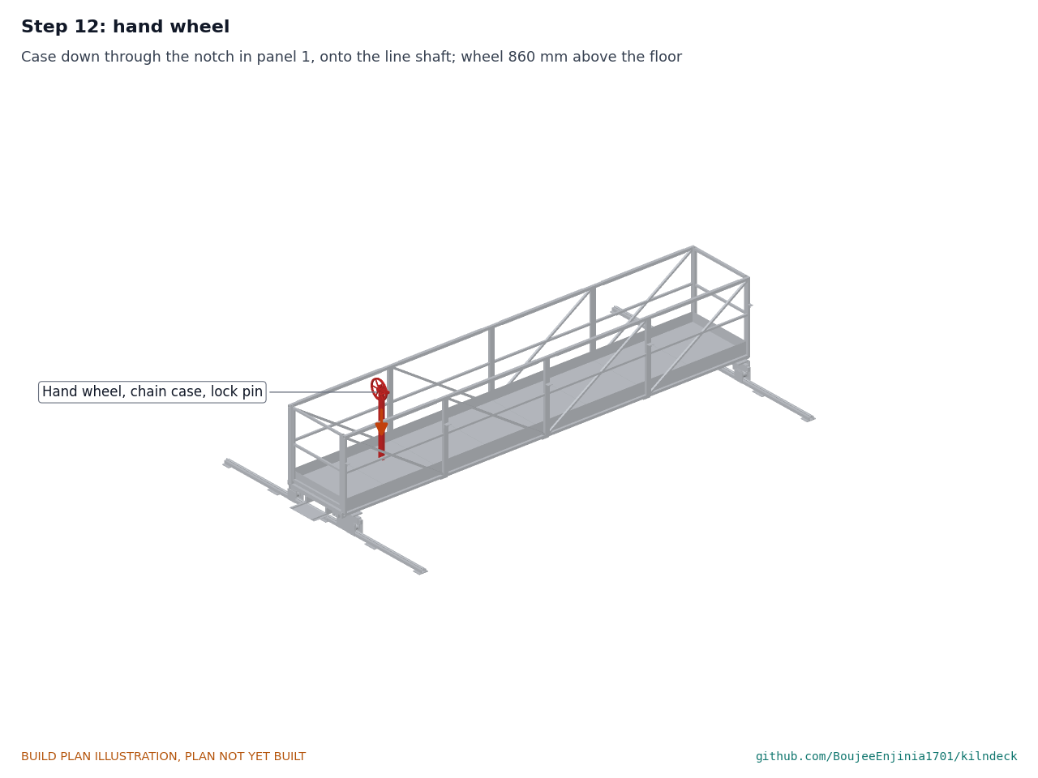
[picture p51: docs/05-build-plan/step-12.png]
Figure 34. Step 12


*Figure 34. Step 12: hand wheel, chain case and lock pin.*

Lower the chain case through the notch in panel 1 onto its sprocket on the line shaft; bolt its foot to the end frame bearer; fit the chain and close the case. Fit the hand wheel and the lock plunger.

### Step 13: carriage rail

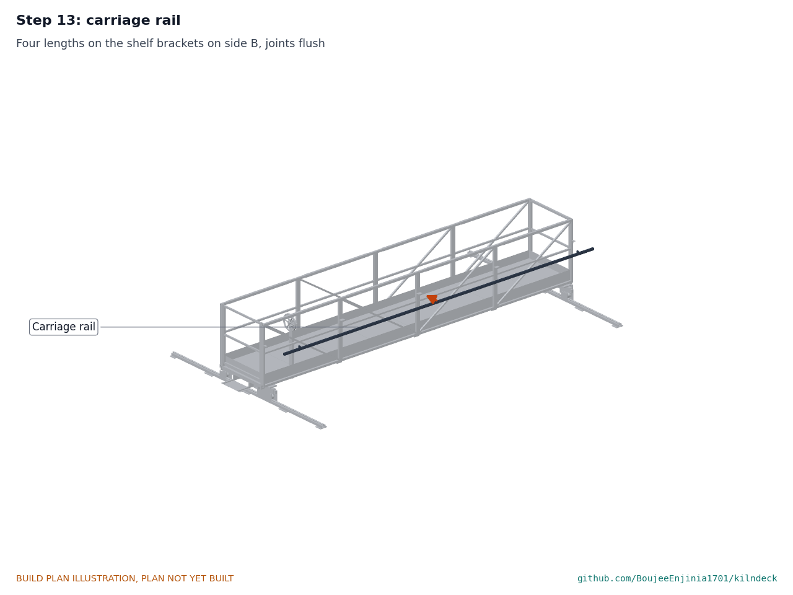
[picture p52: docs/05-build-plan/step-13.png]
Figure 35. Step 13


*Figure 35. Step 13: carriage rail on side B.*

Bolt the four rail lengths on the shelf brackets, joints flush.

### Step 14: carriage frame

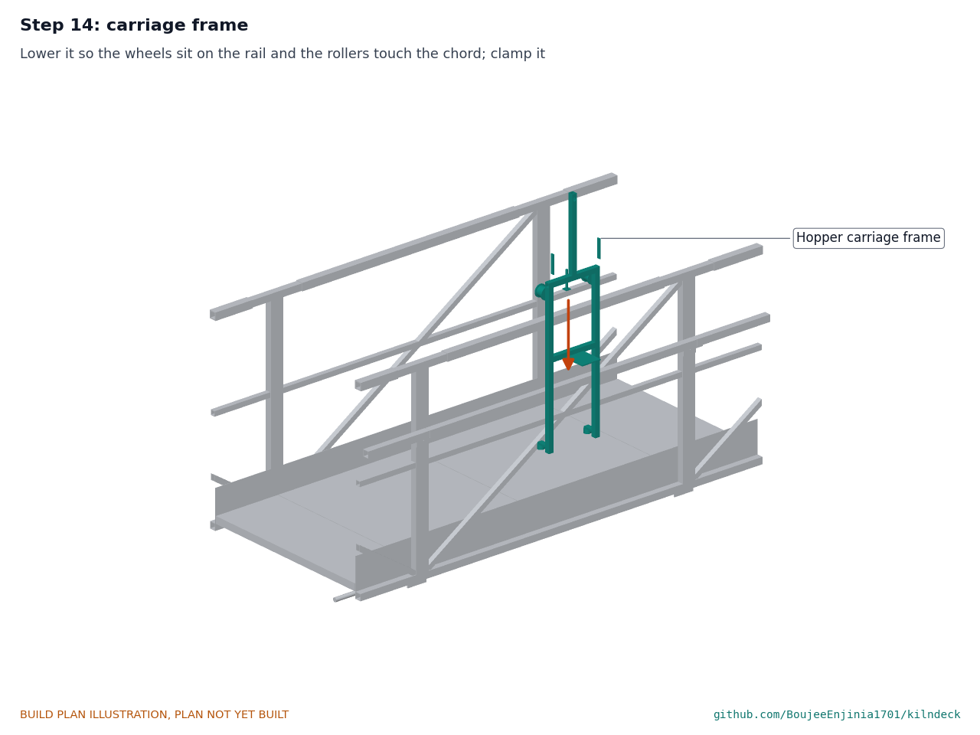
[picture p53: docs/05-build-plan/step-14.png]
Figure 36. Step 14


*Figure 36. Step 14: hopper carriage frame onto its rail.*

Lift the frame over the rail from outside the deck so its wheels sit on the rail and the rollers touch the bottom chord. Tighten the clamp. This lift is done from the wall top or a working platform beside the deck in the cold zone, never from the crust.

### Step 15: hopper

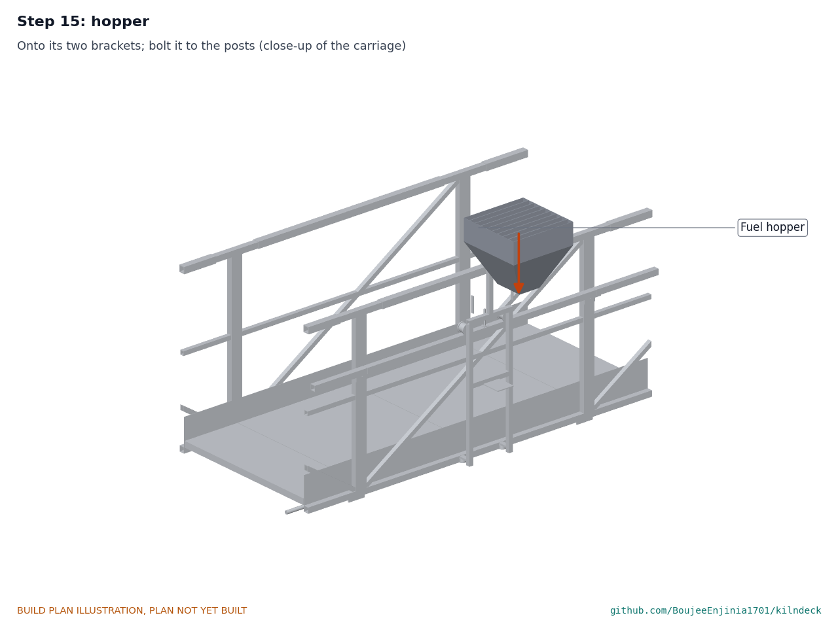
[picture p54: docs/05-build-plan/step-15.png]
Figure 37. Step 15


*Figure 37. Step 15: fuel hopper.*

Set the hopper on its brackets and bolt it to the posts.

### Step 16: metering rotor and crank

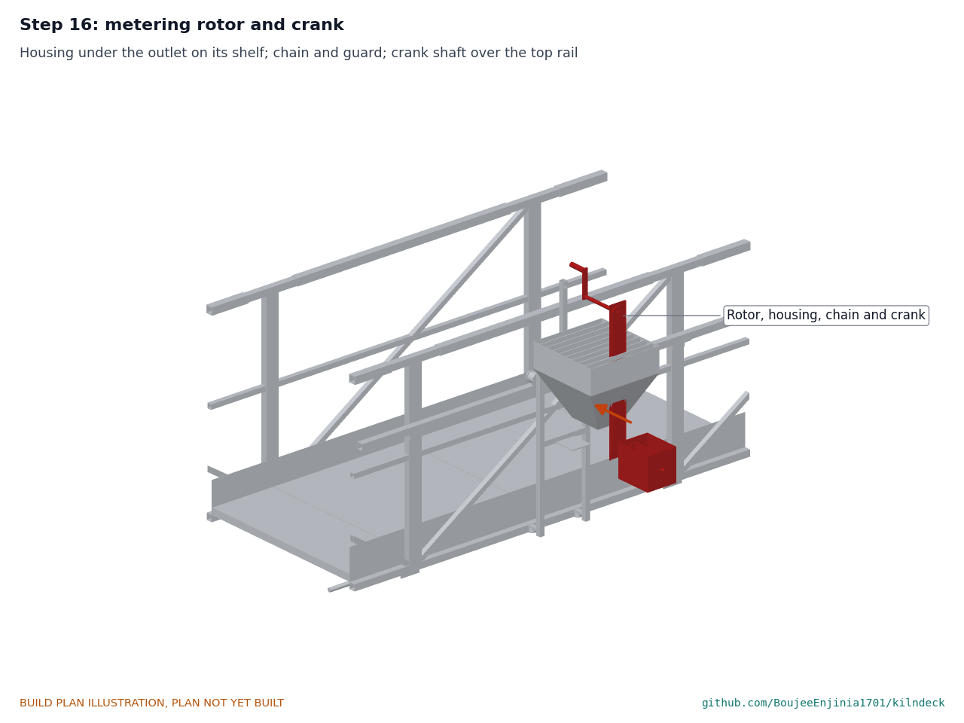
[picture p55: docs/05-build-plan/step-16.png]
Figure 38. Step 16


*Figure 38. Step 16: rotor housing, chain, guard and crank.*

Bolt the housing on its shelf under the outlet; weld the outlet to the housing; fit the chain and guard; pass the crank shaft through the crank post and fit the crank on the deck side.

### Step 17: swing spout

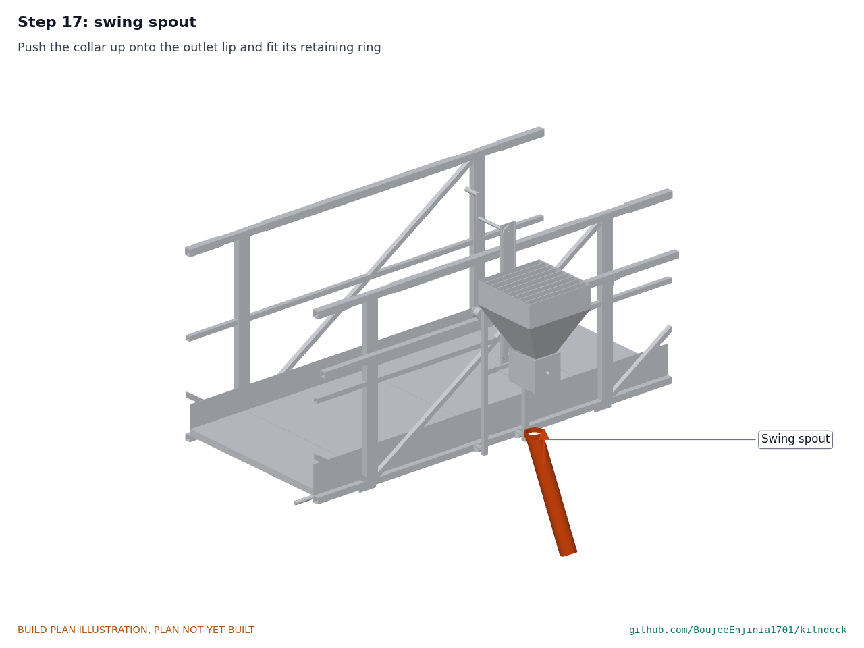
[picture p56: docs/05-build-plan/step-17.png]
Figure 39. Step 17


*Figure 39. Step 17: swing spout.*

Push the collar up onto the outlet lip and fit its retaining ring. The deck is complete.

## 5. First checks

These are listed for TRL 4; a test report records them.

*Table 2. First checks.*

| Check | Requirement | How | Pass when |
| --- | --- | --- | --- |
| Pieces under 40 kg | R12 | Weigh each piece before it goes up | Every piece 40 kg or less |
| Guardrail | R2 | CalRig: 1.5 kN horizontal on the top rail at mid-module, at a splice and at each end post, over the cold zone | No permanent set; movement under load noted |
| Deck proof | R3 | 375 kg of sandbags at mid-span on side B, over the cold zone | No permanent set; deflection noted |
| Track retention | R13 | Roll the empty deck gently into each end stop; lift one wheel 25 mm with a jack | Stops hold; the guards catch the channel |
| Travel force | R4 | Spring balance on the hand wheel rim, deck loaded to 250 kg | 200 N or less |
| Parking lock | R10 | On a track section shimmed to 5 %, pin in | No creep in 10 min |
| Dose | R5 | 20 single pockets of dry coal into a bucket on a scale | Each within 15 % of the mean |
| Spout alignment | R9 | Stop at 10 marked rows; measure spout to hole centre | Within 25 mm |
| Wall bearing | R8 | Survey limit compared with the pad load; load cell under one pad | Below the survey limit |
| Floor temperature | R7 | Contact thermometer log on an operating kiln, day and night | 50 °C or less (expected to fail in full sun) |
| Feeding without stepping on the crust | R1 | Observe 20 rounds on a straight side | No step onto the crust |

## 6. Safety stops

Work stops at each of these points until what is listed is true.

1. **Before laying any track:** a competent person has surveyed the partner kiln and judged the wall tops sound for the pad loads, and set a bearing limit.
2. **Before any wheel goes on a track:** all four end stops are bolted on.
3. **Before anyone stands on the deck:** the floor is complete, the gate closes and latches by itself, the end rail and all splice and bearer bolts are tight, and the deck has passed the guardrail and deck proof loads (TRL 4) over the cold zone.
4. **Before the deck is first moved with the hand wheel:** the chain guards and the sealed chain case are closed, and the lock pin works.
5. **Before the deck is rolled from the cold zone toward the fire:** the track ahead is laid and gauged, nothing is left on the crust, and the fireman wears heat-resistant footwear and gloves.
6. **Before fuel goes into the hopper:** the grille is in place, and the rotor is only ever cleared with the crank, never by hand.
7. **At every row:** the lock pin is in before the carriage clamp is released or the spout is swung.
8. **Never:** work over the fire from outside the deck; open the gate while the deck is moving; stand on the step or carriage.

## 7. Tools, skills and workspace

- A workshop with a flat floor at least 4 x 3 m for the truss jig; cold saw or abrasive saw; pillar drill and magnetic drill for the 32 mm holes; stick welder and a competent welder for the truss, truck and bearer welds; angle grinder; rivet gun; hand taps; spanners for M8 to M12.
- A small lathe for the spout collar (or a local machine shop).
- On the kiln: a level and a long straightedge, a 10 m tape, trestles, ropes, gloves and heat-resistant boots. Two people for every lift.
- Skills: reading the sketches; welding hollow sections; setting out two parallel lines across a trench.

## 8. Where the numbers come from

- Model: `cad/src/model.py` (with constructability checks), exported to `cad/step/` and `cad/stl/`.
- General arrangement: `cad/drawings/KND-DWG-001`; making sketches `cad/drawings/KND-DWG-101` to `KND-DWG-112`.
- Pictures: `cad/src/build_plan_media.py`.
- Calculation note: `docs/04-calcs/01-sizing.md` (KND-CAL-001) and `docs/04-calcs/sizing.py`.
- Bill of materials: `bom/bom.csv`.
- Decisions: `docs/decisions/0001-trl2-review-decisions.md`, `docs/decisions/0002-design-for-construction.md` and `docs/06-design-decisions.md`.

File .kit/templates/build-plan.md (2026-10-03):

---
doc_id: PRJ-BLD-001
title: Project prototype build plan
project: Project name
doc_type: Build plan
version: "0.1"
status: Draft
date: YYYY-MM-DD
author: Amish Chadha
license: CERN-OHL-S-2.0
revisions:
  - version: "0.1"
    date: YYYY-MM-DD
    author: Amish Chadha
    change: First build plan; design made constructable
---

# Project prototype build plan

**Plan, not yet built.** How to build the first proof-of-concept prototype, component by component. Building and testing to it is TRL 4 work. Decisions still to be made are kept in the design decisions register (`docs/06-design-decisions.md`), not here.

## 1. What you are building

Every component, pulled apart and numbered in build order

One short paragraph: what the prototype is, how many components, which are made and which are bought, and the main ways they are made.

## 2. What changed to make it buildable

| Component | The concept had | The buildable design has | Why |
| --- | --- | --- | --- |

## 3. Making the components

### 3.1 Component name

Making sketch

**What it is and what it is made from.**

**How to make it.**

1. Mark out ...
2. Cut ...

**How it fits the parts next to it.**

Close-up of the joint

**Check before moving on.**

## 4. Putting it together

### Step 1: ...

Step 1

## 5. First checks

| Check | Requirement | How | Pass when |
| --- | --- | --- | --- |

## 6. Safety stops

## 7. Tools, skills and workspace

## 8. Where the numbers come from

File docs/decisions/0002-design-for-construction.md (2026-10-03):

---
doc_id: KND-DDR-002
title: KilnDeck design for construction
project: KilnDeck
doc_type: Design decision record
version: "0.1"
status: Draft
date: '2026-10-03'
author: Amish Chadha
license: CERN-OHL-S-2.0
revisions:
- version: "0.1"
  date: '2026-10-03'
  author: Amish Chadha
  change: Design made constructable for the prototype build plan (KND-BLD-001); decided under Amish's 2026-10-03 pre-approval
---

# 0002: Design for construction

- **Date:** 2026-10-03
- **Status:** decided. Decided by Amish under his pre-approval of 2026-10-03: "start with the first 14 repos from the list of 29 projects. I pre-approve the batch runs along with any recommendations you come up with. I also accept any cost overruns or variations from the assumed scope cost."

## Context

STANDARDS section 18 requires the design to be constructable before TRL 3: every part made by a stated process, every joint fixed, and an order of assembly that works (Amish, 2026-09-30: "fix the design assumptions to match and be physically feasible"). The concept of KND-PRC-001 v0.1 named eight components but no sections, joints or fixings. Writing the build plan KND-BLD-001 turned each into a part that can be cut, welded, drilled or bought, and the model `cad/src/model.py` was checked with build123d for overlaps between every pair of neighbouring parts (none left), clearances and the mass of every piece carried up the kiln.

## Changes

*Table 1. Changes from the concept, with the reason for each.*

| # | Component | The concept had | The constructable design has | Why |
| --- | --- | --- | --- | --- |
| C1 | Track | "Rails on supports" bearing on the walls | 3 m modules of UPN 80 channel lying flanges down with a 20 mm round bar welded along the web; 10 mm levelling pads every 1.0 m; slotted fishplates and 6 mm gaps at joints | Stock sections, 33 kg modules two people can carry, and joints that slide 3.6 mm as the track heats by 100 K |
| C2 | Track ends | Nothing | Bolted 200 mm end stops with rubber faces on every track end | The deck must not run off the end of a track (new R13) |
| C3 | End trucks | Not defined | RHS 100 x 50 x 4 beam, 1.2 m wheelbase, wheel forks, seat plates for the truss feet, rubber buffers, derailment guards 24 mm either side of the track channel; boarding step on the outer truck | A lifted or broken wheel lands the truck on the guards over the track, never on the crust |
| C4 | Wheels | "Flanged wheels" | Bought 100 mm U-groove gate wheels rated at least 500 kg. Outer-wall wheels have a 24 mm groove and guide the deck; inner-wall wheels have a 44 mm groove so the deck floats 12 mm either way | The deck grows about 4.8 mm across the trench when it warms by 60 K, and the walls are not built to a gauge tolerance |
| C5 | Deck and guardrail | A standing platform with a separate guardrail | Two side trusses whose top chords are the top rails, each in four bolted 1,725 mm modules of 37 to 39 kg; 1.1 m top rail, knee rail and toe board | The deck must span 6.6 m; a 1.14 m deep truss does it at 11 MPa and 0.5 mm deflection, and the guardrail costs nothing extra |
| C6 | Stiff posts | Not defined | Five frame bearers bolted to cleats on the chords with four M12 bolts each end, making U-frames at the ends and splices | A 1 kN push on the top rail at a splice puts 1.1 kN m into the post foot; the U-frame carries it into the floor |
| C7 | Floor | "Insulated floor" | Eight bolted panels: 40 mm angle frame, 2 mm steel tread, 37 mm calcium silicate board, 1 mm aluminium underside; 30 kg each on nine bearers | Light enough to carry; the reflective underside cuts the heat from the crust |
| C8 | Deck ends | Open | Inner end rail; outer end gate on self-closing spring hinges that opens only inward | The fireman boards from the outer wall top; the gate cannot be left open or open over the drop |
| C9 | Moving the deck and the parking brake | Hand-pushed deck; a separate brake | Hand wheel at the outer end driving a 25 mm line shaft under the floor, with a chain drive to one wheel at each end; a spring lock pin in the hand wheel rim is the parking brake | Both ends move together so the deck cannot skew; the lock holds both driven wheels (727 N against 484 N on a 5 % grade) |
| C10 | Hopper mounting | Hopper on the deck | Hopper carriage on its own rail along the outside of truss B, with top wheels and guide rollers on the chord, and a screw clamp | Keeps the floor whole and lets one hopper serve every hole in the row |
| C11 | Hopper | A hopper | 52 L, 2 mm sheet, with a bar grille (44 mm gaps) across the top | A hand cannot reach the rotor; lumps over about 44 mm stay out |
| C12 | Metering rotor | A rotor turned by hand at the hopper | Four-pocket rotor in a welded housing; chain up to a crank over the top rail on the deck side; chain guard | The fireman turns it without leaning over the guardrail |
| C13 | Spout | A swing spout | 100 mm tube on a turned collar that swivels under the housing; outlet 1,225 mm from the deck centre line, 150 mm above the wall top | A plain swivel that can be turned on a small lathe |
| C14 | Hot handrails | "Insulated grips" | Silicone sleeves rated to 200 °C on both top rails between the posts | A bought part that fits a 40 mm square rail |
| C15 | Assembly | Not worked out | The deck is assembled on trestles over the cold zone of the kiln (where bricks are set or drawn, with no fire beneath) and rolled to the fire only when complete | No one works over the fire during assembly |

## Related choices made at the same time

| # | Item | Decision | What would change it |
| --- | --- | --- | --- |
| A1 | Wheel rating | At least 500 kg per wheel; the worst wheel load is about 447 kg with a 1.25 dynamic factor | A lighter deck at TRL 4 |
| A2 | Wall bearing limit until the survey | Interim limit of 0.20 MPa under a pad (conservative for an old brick wall in mud or lime mortar); the design gives 0.15 MPa | A structural survey of the partner kiln setting a measured limit |
| A3 | Shade over the deck | No canopy on the first prototype. R7 is not met in full sun (floor top about 74 °C at 45 °C air) and is reported as such; the fireman keeps heat-resistant footwear | A wind-load check of a canopy on the rolling deck and floor temperatures logged at TRL 4 |
| A4 | Curved ends of the kiln | Not served by the prototype; R1 is met on the straight sides only | A later curved or turntable track design |

## Consequences

- `cad/src/model.py`, the drawing KND-DWG-001 (Rev P1), the STEP and STL files, the concept media and the BOM are generated from the constructable design. `design_state: constructable` is set in `project.yaml`.
- The parts cost rises from no estimate at TRL 1 to USD 2,627, USD 873 under the USD 3,500 value-engineering target.
- KND-CAL-001 was run on the constructable model; every requirement except R7 (full sun) and R1 (curved ends) is met on paper, R8 is met against the interim limit only, and R5 can only be checked at TRL 4.
- No change alters the pitch. The safety case is stronger, not weaker: higher guardrail, inward gate, end stops, derailment guards, a positive lock and a guarded rotor.

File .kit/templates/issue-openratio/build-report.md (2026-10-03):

---
name: Build report
about: Tell us what happened when you built, printed or tested part of this design
title: "Build report: "
labels: build-report
---

This is a research and educational prototype, not a medical device. It is a TRL 3 concept and is not released for fabrication. If you build any part of it, you do so at your own risk. Reports help everyone.

**What you built** (part, sub-assembly or test)

**Materials, tools and settings**

**What worked**

**What did not work, with photos or measurements if you have them**

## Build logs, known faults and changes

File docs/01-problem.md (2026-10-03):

---
doc_id: KND-PRB-001
title: KilnDeck problem statement
project: KilnDeck
doc_type: Problem statement
version: "0.2"
status: Draft
date: '2026-10-03'
author: Amish Chadha
license: CERN-OHL-S-2.0
revisions:
- version: "0.1"
  date: '2026-09-30'
  author: Amish Chadha
  change: Initial scaffold
- version: "0.2"
  date: '2026-10-03'
  author: Amish Chadha
  change: TRL 2 and 3 update; kiln geometry stated as working assumptions; open questions answered or carried to the co-design partner (KND-DDR-001)
---

# KilnDeck problem statement

On most South Asian brick kilns, firing is still a manual job done on foot, on top of the fire. The fuel feeding method has barely changed, and neither has where the fireman stands.

## The problem

In a fixed-chimney bull's trench kiln, two firemen standing on top of the kiln feed solid fuel through feed holes every 15 to 20 minutes ([Greentech, 2014](https://www.shareweb.ch/site/Climate-Change-and-Environment/about%20us/about%20gpcc/Documents/01%20Fixed%20Chimney%20Bulls%20Trench%20Kiln%20(FCBTK).pdf)). They work in pairs, in shifts of six to eight hours, in the sun with no shade, and receive no gloves or masks ([The Migration Story](https://themigrationstory.com/post/braving-the-heat-to-bake-bricks/)).

Existing improvements target fuel, not footing. Stanford's Luby Lab and BUET built motorised automatic coal feeders; pilots found wet coal clogging the feeder and small motors overheating under load ([Luby Lab](https://lubylab.stanford.edu/automatic-coal-feeder)). A 1924 German patent describes a rotating-disc fuel charger for brick kilns, now long expired ([US1506924A](https://patents.google.com/patent/US1506924A/en)). None of these give the fireman somewhere safe to stand while he feeds.

## Users and context

*Table 1. Users.*

| User | Need | Context |
| --- | --- | --- |
| Kiln firemen | Feed fuel at every hole without standing on the crust, and with less heat on the feet | Kiln top in shifts of 6 to 8 hours, day and night, high ambient heat |
| Kiln owners and managers | A low-cost addition that fits the existing kiln and does not slow production | Seasonal operation, thin margins, local fabrication |
| Local fabricators | Drawings for track, deck and hopper from stock steel | Small workshops in brick-making districts |
| Clean-kiln and worker rights programmes | A safety measure that fits alongside fuel-efficiency training | NGO, research and government programmes |

## Operating environment

- Top of an operating bull's trench kiln: a trench of bricks between an outer wall and an inner wall, covered by an ash crust with feed holes, around a central chimney. The fire moves 6 to 10 m along the kiln a day, on a circuit of 180 to 220 m ([Greentech, 2014](https://www.shareweb.ch/site/Climate-Change-and-Environment/about%20us/about%20gpcc/Documents/01%20Fixed%20Chimney%20Bulls%20Trench%20Kiln%20(FCBTK).pdf)); whole kilns are about 20 to 30 m wide and 75 to 120 m long ([BrickGuru](https://www.brickguru.in/en/knowledge-brief/what-is-a-fixed-chimney-bulls-trench-kiln-fcbtk/)).
- Working assumptions until a survey of the partner kiln (KND-CAL-001, section 1): a trench 6.0 m wide between wall faces; wall tops at least 0.6 m wide and level with the crust within 100 mm; feed holes about 150 mm across, about 1.0 m apart along and across the kiln; crust surface about 150 °C, up to 250 °C at hot spots.
- Radiant and conducted heat from the kiln top; ambient air up to about 45 °C (113 °F) in summer ([The Migration Story](https://themigrationstory.com/post/braving-the-heat-to-bake-bricks/)).
- Coal dust, ash, smoke and rain during the firing season.
- Night work under poor lighting.
- No power at the kiln top.

## Constraints

- Value-engineering target for the prototype parts: USD 3,500 (a hypothetical control target, not a spending limit).
- Manual only: no motor; the deck is moved and the fuel is metered by hand.
- Track and supports bear only on sound kiln walls, never on the crust, within a bearing limit set by a survey of each kiln.
- Buildable with hand tools, a drill and a small stick welder from stock steel sections.
- Every piece carried up the kiln weighs 40 kg (88 lb) or less, so two people can carry it.
- Open design: hardware under CERN-OHL-S-2.0, any calculators under MIT.

> **Safety:** The deck carries a person over a burning kiln. A fall through the guardrail, a deck running off its track, a crushed hand in the drive or the rotor, and heat on the feet are the hazards this design must control. It is published as an open engineering reference, not certified equipment; kiln owners and builders are responsible for their own structural checks and risk assessment.

## Out of scope

- Motorised or automatic feeders.
- Kiln conversion (for example to zigzag firing) and emissions control.
- Brick moulding, loading and unloading work.
- Labour rights, wages and bonded labour, which need legal and social action rather than hardware.
- The curved ends of the kiln, in this first prototype (KND-DDR-002, A4).

## Prior work

*Table 2. Prior work.*

| Prior work | What it does | Gap for these users | Source |
| --- | --- | --- | --- |
| Automatic coal feeder (Luby Lab, Stanford, and BUET) | Motorised funnel feeder for kiln feed holes, piloted in Jessore, Bangladesh | Powered; clogging with wet coal and motor overheating reported; does not give the fireman a safe place to stand | [link](https://lubylab.stanford.edu/automatic-coal-feeder) |
| US1506924A, fuel-charging device for brick kilns (1924, expired) | Coal hopper with a rotating bottom disc that delivers fuel into the stoking hole | Fixed charger at a single hole; no deck, rails or guardrail | [link](https://patents.google.com/patent/US1506924A/en) |
| Brick kiln intervention trial (Luby Lab) | Training in continuous fuel feeding and better brick setting across 300 kilns | Changes practice, not equipment; firemen still stand on the crust | [link](https://lubylab.stanford.edu/brick-kiln-intervention-trial) |
| Standard firing practice (Greentech factsheet) | Two firemen on the kiln top feed fuel by hand through feed holes | The status quo that KilnDeck changes | [link](https://www.shareweb.ch/site/Climate-Change-and-Environment/about%20us/about%20gpcc/Documents/01%20Fixed%20Chimney%20Bulls%20Trench%20Kiln%20(FCBTK).pdf) |

## Co-design

A clean-kiln programme or kiln owners' association with access to operating kilns and firemen, ideally one already running fuel-feeding training, so the deck can be tried with real firemen during a firing season. First candidate to approach: a clean-kiln research programme in Bangladesh (for example the Stanford and BUET kiln team); second: a kiln owners' association in Punjab, Pakistan (KND-DDR-001, D8). Neither has been approached.

Co-design checklist:

- [ ] Survey of one partner kiln: trench width, wall-top width and condition, crust level and temperature, feed hole grid and lids.
- [ ] Interviews with firemen on the hazards they see and whether they would use a deck.
- [ ] Fuel used at that kiln (coal, biomass or both) and how it reaches the kiln top.
- [ ] Owner's view on where fuel stock is kept and how the track is moved with the fire.

## Open questions, answered at TRL 2 and 3

*Table 3. The scaffold's open questions.*

| Question | Answer | Source |
| --- | --- | --- |
| Track all the way round, or sections that move with the fire? | Sections on the straight sides, laid ahead of the fire and lifted behind it | KND-DDR-001, D2 |
| How hot do the rails get, and do they need sliding joints? | Yes: slotted fishplates with 6 mm gaps take 3.6 mm per module at +100 K; the deck floats 12 mm on its inner wheels | KND-CAL-001, section 13 |
| Coal and biomass? | Both; about 0.49 kg of coal or 0.15 kg of biomass per rotor pocket (estimates) | KND-CAL-001, section 4 |
| What do firemen see as the hazards, and would they use a deck? | Not a design question; it is the first co-design task above | Co-design |
| Does the rotor clog with wet coal? | Smooth hopper seams, a 40 mm lump limit and a crank that can be turned back reduce the risk; only a trial can answer it | KND-REQ-001, R5 (TRL 4) |

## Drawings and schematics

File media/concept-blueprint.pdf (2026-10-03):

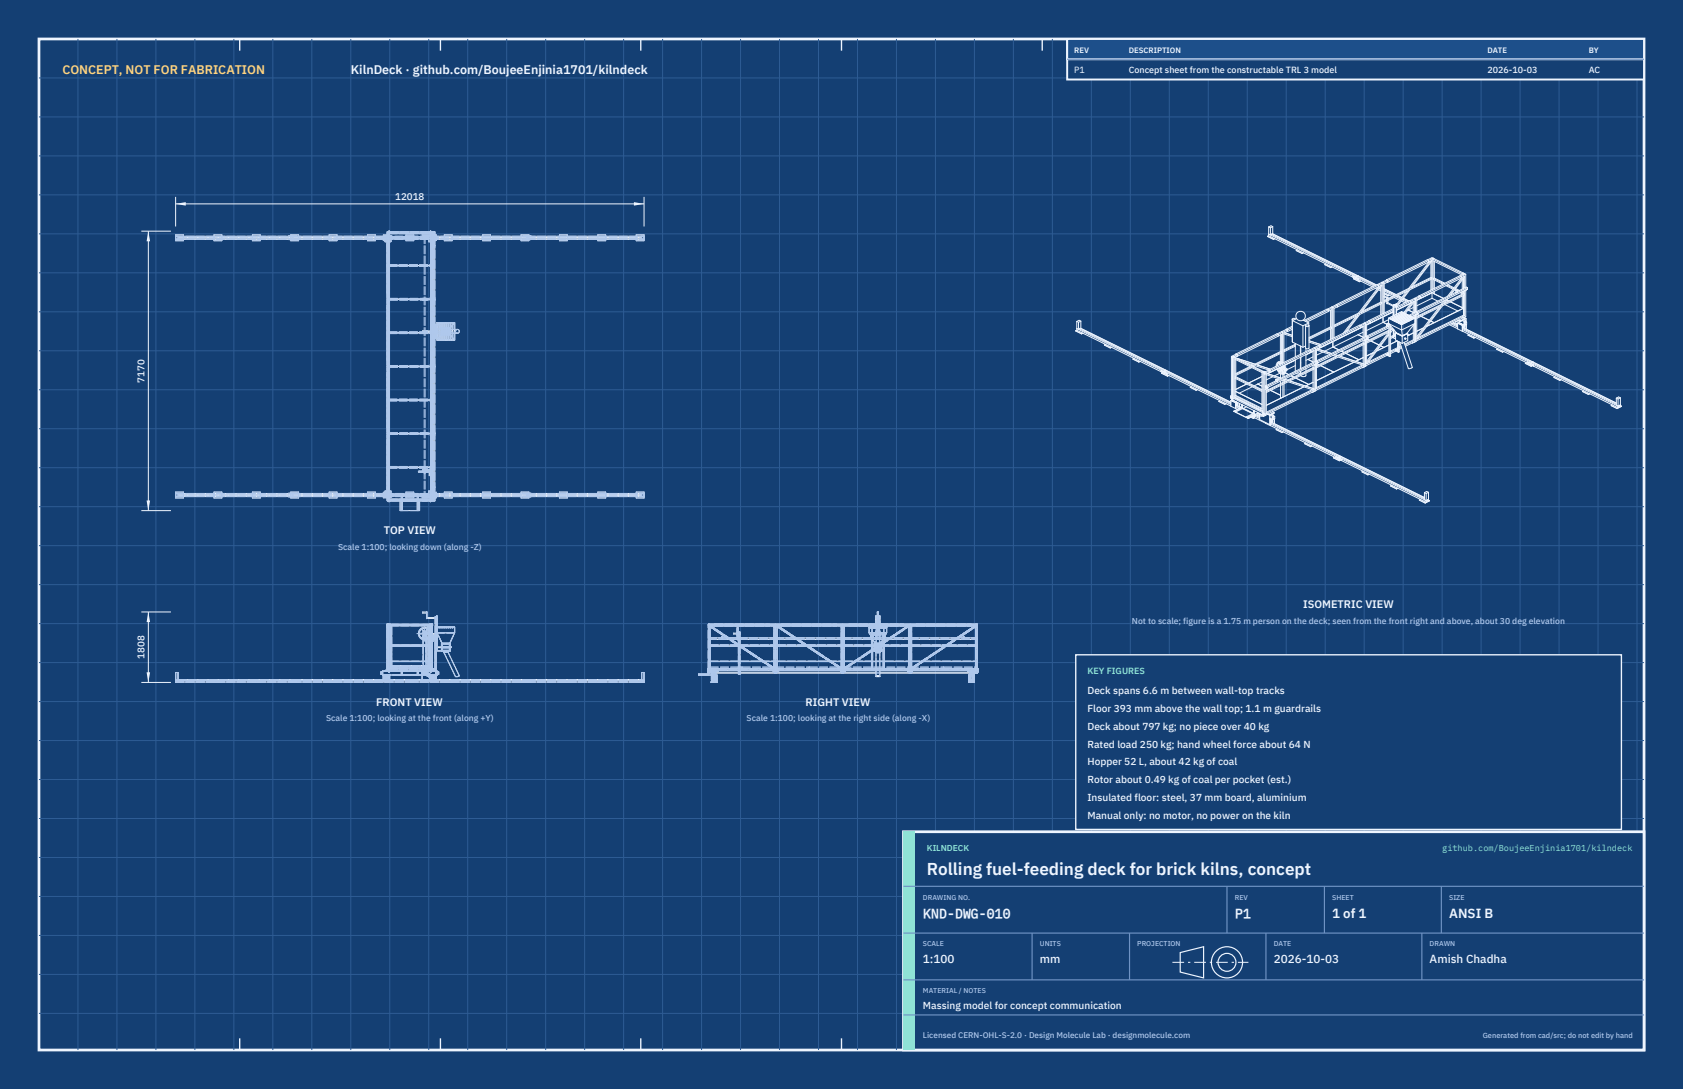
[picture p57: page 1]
CONCEPT, NOT FOR FABRICATION; KilnDeck · github.com/BoujeeEnjinia1701/kilndeck; FRONT VIEW; TOP VIEW; RIGHT VIEW; ISOMETRIC VIEW; REV; DESCRIPTION; DATE; Concept sheet from the constructable TRL 3 model; KILNDECK; github.com/BoujeeEnjinia1701/kilndeck; DRAWING NO. KND-DWG-010; REV P1; SHEET 1 of 1; SIZE ANSI B; SCALE 1:100; UNITS mm; PROJECTION; DRAWN Amish Chadha; Licensed CERN-OHL-S-2.0 · Design Molecule Lab · designmolecule.com; Generated from cad/src; do not edit by hand

Scale 1:100; looking down (along -Z)

Not to scale; figure is a 1.75 m person on the deck; seen from the front right and above, about 30 deg elevation

KEY FIGURES
Deck spans 6.6 m between wall-top tracks
Floor 393 mm above the wall top; 1.1 m guardrails
Deck about 797 kg; no piece over 40 kg
Rated load 250 kg; hand wheel force about 64 N
Hopper 52 L, about 42 kg of coal
Rotor about 0.49 kg of coal per pocket (est.)
Insulated floor: steel, 37 mm board, aluminium
Manual only: no motor, no power on the kiln

Scale 1:100; looking at the front (along +Y)

Scale 1:100; looking at the right side (along -X)

Rolling fuel-feeding deck for brick kilns, concept

MATERIAL / NOTES
Massing model for concept communication

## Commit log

2026-10-03 KilnDeck at TRL 3: constructable design (kit 1.7.0)
    Problem, concept and requirements; sizing calculations; CAD model, STEP and STL; general arrangement drawing; bill of materials; build plan with making sketches, joint close-ups and step pictures; design decisions register (all decided under Amish's 2026-10-03 pre-approval); TRL 2 and TRL 3 review; photoreal renders and storefront card. Private until Amish opens it.
    [bom.csv, kilndeck-assembly.step, kilndeck-carriage.step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]
2026-10-29 Kit 1.9.1 upgrade: pipeline documents and detailed CAD for every option
    STEM check with fixes under the standing instruction and an independent
    review, concept options scored against the user requirements, URS, PRS,
    RTM, REG, FEA, RSK, MKT, PLN and DDR, every option modelled at D3 with
    cad/fidelity.json passing, and the concept options picture rendered with
    Blender Cycles on Amish's Mac. Concept choices stay proposed, awaiting
    Amish.
    Claude-Session: https://claude.ai/code/session_01LppsZSzPTJWTBAV5wh1Goq
2026-11-05 Keep every STEP file under GitHub's 100 MB limit
    The decisions pass re-exported option A as one 106 MB assembly STEP,
    which GitHub rejects. cad/src/slim_step.py splits it again into
    A-assembly (36.9 MB), A-assembly-2 (27.3 MB), A-fasteners (30.8 MB) and
    A-welds (13.9 MB), all in the one assembly frame. Carries Amish's
    2026-10-30 decisions, which the rejected push held. CAD fidelity D3
    rechecked; PDFs rebuilt.
    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

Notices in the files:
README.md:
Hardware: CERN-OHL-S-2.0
